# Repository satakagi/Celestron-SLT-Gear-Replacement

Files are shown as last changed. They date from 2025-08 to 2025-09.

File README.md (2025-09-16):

# Celestron NexStar SLT Geared Motor Replacement Gear

This project provides a 3D-printable replacement for a specific plastic gear within the **Celestron "SLT-F00-1A"** geared motor, commonly found in NexStar SLT, GT, and 4SE/5SE series telescopes. "SLT-F00-1B" may be compatible successor assembly. These motors may be also compatible with mounts from SkyWatcher SynScan AZ and Orion Starseeker III.

The original plastic gear is prone to wear, which often necessitates the full replacement of the geared motor. Since these motors are frequently out of stock, this project offers a durable, self-manufactured solution.

---

### Disclaimer: Use at Your Own Risk

This design is released under the **[TAPR Open Hardware License](https://tapr.org/the-tapr-open-hardware-license/)**. By using this design, you acknowledge that you are responsible for the manufacturing and use of the replacement gear. The creator of this project is not responsible for any damage to equipment or injury that may result from the use of this design.

---

### Identifying the Problem Gear

The target of this project is the **second-stage spur gear** in the gearbox. This gear is positioned directly after the pinion gear on the motor shaft and is often the first to show significant wear due to repeated use.

* You should replace this gear if:
    * The telescope's mount fails to rotate even though the motor can be heard running.
    * The telescope's mount slips or fails to track accurately.
    * The teeth on the gear are visibly worn down or chipped.

<div align="center">
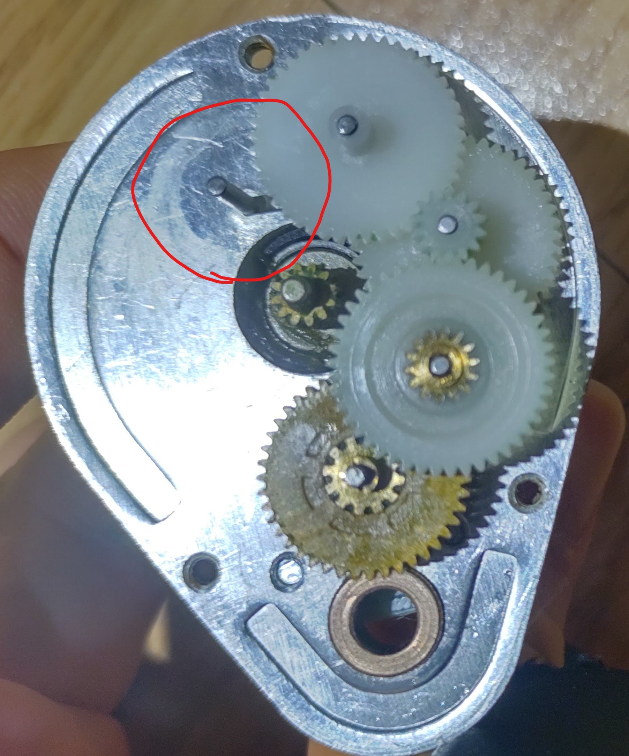
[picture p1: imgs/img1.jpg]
Celestron geared motor with the target gear highlighted.

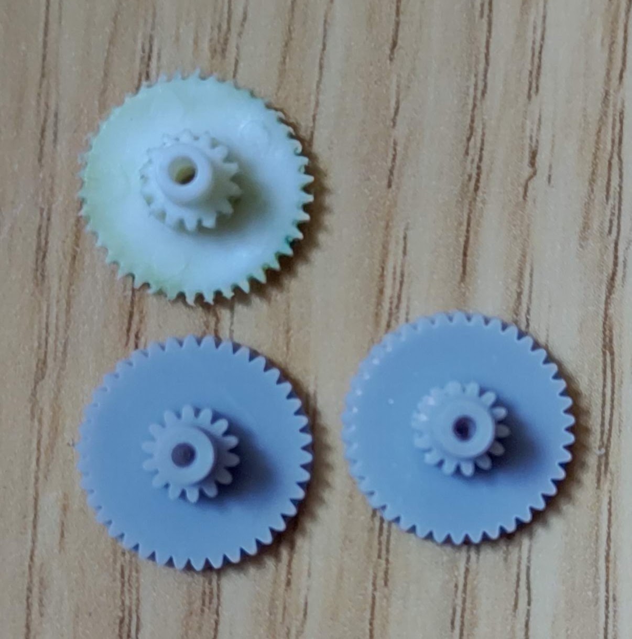
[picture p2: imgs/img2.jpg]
Damaged original gear and a 3D-printed resin gear.

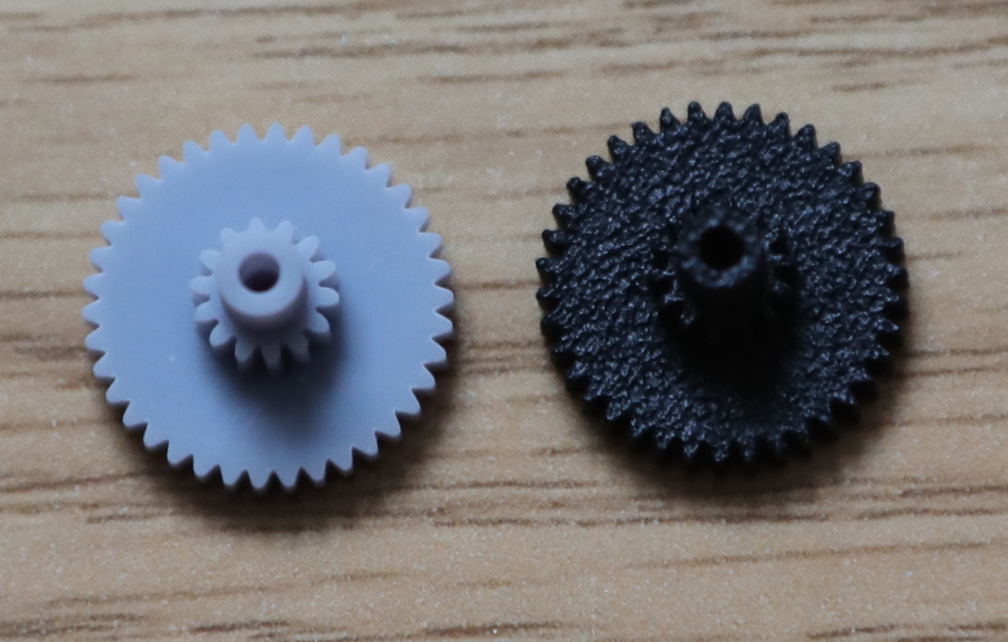
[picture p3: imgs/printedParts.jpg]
3D-printed resin gear.


</div>

* Left image: The replacement gear's location inside the geared motor
* Center image: A damaged original gear and a 3D-printed resin gears
* Right image: Left(gray): resin by SLA,  Right(black): PA12 nylon by MJF

---

### Recommended Manufacturing Method and Material

Initial prototypes of this gear were successfully printed using an SLA (stereolithography) printer, which confirmed the design's fit and function. However, due to the low durability of typical SLA resins, this material is not recommended for long-term use.

For a durable and functional final product, the recommended material is **PA12 nylon using the Multi Jet Fusion (MJF) method**. This material is known for its excellent mechanical strength, high wear resistance, and toughness, making it ideal for gears.

---

### Design Information

The design is a two-stage spur gear with the following specifications:

* **Larger Gear:**
    * Teeth: 38t
    * Outer Diameter: ~13mm
    * Thickness: 2mm
    * Shaft Hole Diameter: 1.5mm
    * Module: ~0.33 (estimated)
* **Smaller Gear:**
    * Teeth: 14t
    * Outer Diameter: ~5mm
    * Thickness: 2.5mm
    * Shaft Hole Diameter: 1.5mm
    * Module: ~0.33 (estimated)

*Note: The module of 0.33 is not a standard value, so high-precision manufacturing (such as MJF) is essential to ensure proper gear meshing.*

---

### Files Included in This Repository

* [NexstarSLTGearbox2ndGear.stl](NexstarSLTGearbox2ndGear.stl): The 3D model file for printing.
* [NexstarSLTGearbox2ndGear.f3d](NexstarSLTGearbox2ndGear.f3d): The original Fusion 360 design file for modification.
* [LICENSE](LICENSE): The full text of the TAPR Open Hardware License.

---

### How to Replace the Gear

1.  Disassemble the Celestron "SLT-F00-1A" geared motor.
2.  Locate the worn second gear (refer to the images in this repository).
3.  Carefully remove the old gear from the shaft.
4.  Test the fit of the new 3D-printed gear on the 1.5mm shaft. The gear should slide onto the shaft with a minimal amount of friction, without any noticeable play or "wobble."
    * **If the fit is too tight:** Use a **1.5mm drill bit by hand** to gently ream the hole until the gear slides on smoothly. **Do not use a power drill**, as this can easily over-enlarge the hole and ruin the fit.
    * **If the fit is too loose:** The gear will not transfer power effectively. This indicates a problem with the print's dimensional accuracy. You may need to adjust your printer's settings or try a different material.
5.  With the new gear properly seated, reassemble the geared motor, ensuring all other components are in their correct positions.

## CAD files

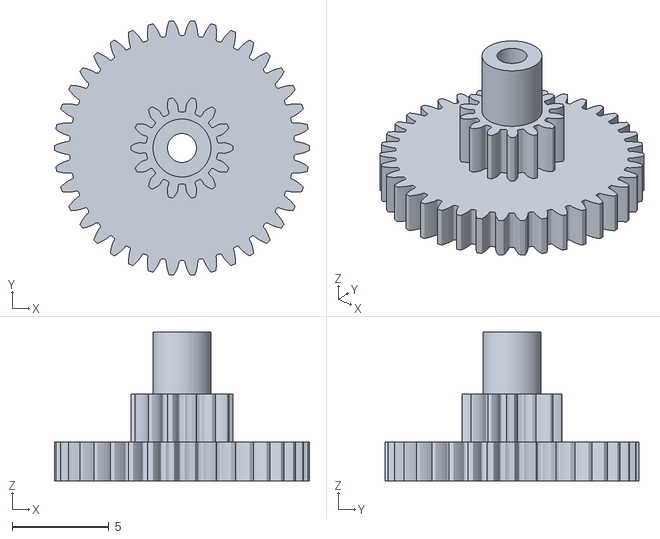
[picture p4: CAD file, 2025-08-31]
NexstarSLTGearbox2ndGear.stl
13.2 x 13.2 x 7.70

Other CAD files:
NexstarSLTGearbox2ndGear.f3d
